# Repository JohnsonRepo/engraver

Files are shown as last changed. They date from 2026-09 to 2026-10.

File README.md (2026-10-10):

# engraver

CNC-Engraver mit Diodenlaser — Konstruktionsskripte, Prüfwerkzeuge und Notizen.

## Aufbau der Maschine

| Ebene | Aufbau |
|---|---|
| Gestell | 2 × 2060 Aluprofil quer (600 mm, 435 mm Mitte zu Mitte, das vordere 35 mm hinter dem Ende der 2040), darauf 2 × 2040 Aluprofil längs (600 mm), alle hochkant; steht auf 4 gedruckten Führungsfüßen 25,3 mm über dem Tisch, dazwischen die Opferplatte |
| Y-Achse | 2 Linearführungen MGN12H (Schienen 500 mm) oben auf den 2040ern; GT2-Riemen in den oberen Nuten der 2040, vorn je Seite ein NEMA 17 mit dem Ritzel direkt auf der Welle, mittig zur 2040 |
| Portal | Y-Schlitten auf den MGN12H-Wagen, dazwischen ein 2020-V-Slot-Profil (500 mm); Y-Schienen 514 mm Mitte zu Mitte |
| X-Achse | Linearführung MGN15H (Schiene 450 mm) am Portalprofil, GT2-Riemen: NEMA 17 links, Umlenkung mit Spanner rechts |
| Z-Achse | Toolhead am MGN15H-Wagen: eigene MGN9-Führung, NEMA 17 über Tr8×2-Spindel |
| Werkzeug | Diodenlaser am Z-Schlitten |
| Steuerung | Arduino Uno R3 + CNC Shield V3 + 4 × TMC2209 (vorhanden), GRBL 1.1, A-Achse klont Y; ohne PC über einen Raspberry Pi Zero 2 W mit CNCjs |

## Inhalt

```
fusion/ToolheadZ/              Baugruppe: kompletter Toolhead mit Z-Achse  ← aktuell
fusion/Portal/                 Baugruppe: Y-Schlitten, Y-Klemmtürme, X-Antrieb, Y-Antrieb mit Y-Motorhalter, Endschalter X und Y, Wanne der X-Energiekette
fusion/Elektronik/             Gehäuse für Uno + CNC Shield, Wandler, Wago; Deckel als Haube mit Lüfter (Rev. 3)  ← neu
fusion/NotAus/                 Gehäuse für den Not-Aus vorn am vorderen 2060  ← neu
fusion/Kabelhalter/            Kabelhalter für die untere Seitennut außen an den 2040  ← neu
fusion/PiHalter/               Halter mit Haube für Pi Zero 2 W und 5-V-Wandler an der Rückseite des hinteren 2060  ← neu
fusion/Opferplatte/            Führungsfüße unter den 2060 und Riegel für die Opferplatte (Spanplatte)  ← neu
fusion/Spannmittel/           Anschlagwinkel, Exzenter und Niederhalter für das Werkstück auf der Opferplatte  ← neu
fusion/ToolheadGrundplatte/    nur die Laserplatte (vom Toolhead überholt)
stl/                           druckfertige STL ohne Fusion: Kasten und Haube des Elektronik-Gehäuses, Kabelhalter, Pi-Halter und seine Haube
pi/                            Pi: Einrichtungsskript, CNCjs-Konfiguration mit Makros, Dienst, sudoers, WLAN-Energiesparen aus
docs/toolhead-z.md             Maßkette, Antrieb, Montage, Druck, Prüfliste
docs/portal-y-schlitten.md     Y-Schlitten, Y- und X-Riemen, Klemmen, Montage, Druck
docs/portal-y-schlitten.svg    Draufsicht auf beide Portalenden, Schnitte durch Klemmen und Umlenkung
docs/toolhead-z-layout.svg     maßstäbliche Seiten- und Vorderansicht
docs/toolhead-z-antrieb.svg    Skizze des Z-Antriebs: Motor, Kupplung, Spindel, Garnitur
docs/toolhead-grundplatte.md   Doku der Einzelplatte
docs/elektronik.md             Platz, Gehäuse, Leistung, Endschalter, Kabel, Anschlussplan
docs/elektronik-platz.svg      Draufsicht und Seitenansicht: Elektronikfach, Ketten, Kabelwege
docs/elektronik-anschluss.svg  Anschlussplan mit Kabelnummern W1–W19 und Kabelliste
docs/elektronik-verkabelung.svg  Verkabelung Schritt für Schritt: jede Ader von Klemme zu Klemme
docs/motoren-anschluss.svg     Motoren anschließen: Steckplätze am Shield, Adern je Achse
docs/verkabelung.md            Verkabelung: Kabelliste, Anschlussliste, Klemmen, Schritt für Schritt, Inbetriebnahme, GRBL
docs/elektronik-box.svg        Elektronik-Gehäuse von oben: Uno, Lüfter, Verteiler, Kabelwege
docs/endschalter.md            Endschalter X und Y: Halter, Fahnen, Montage, Einstellen, GRBL
docs/endschalter.svg           Endschalter: Y von hinten und von außen, X von vorn und von oben, Klammer X
docs/notaus.md                 Not-Aus: Taster, Lage, Gehäuse, Montage, Druck
docs/notaus.svg                Not-Aus-Gehäuse von vorn, im Schnitt und von oben
docs/kabelhalter.md            Kabelhalter: Rinne, Kabel, Plätze links und rechts, Montage, Druck
docs/kabelhalter.svg           Kabelhalter im Schnitt am 2040 und seine Plätze
docs/pi.md                     Pi: Maschine ohne PC über CNCjs — Teile, Halter, Strom, Einrichten, LightBurn, Ablauf, Fehlersuche
docs/pihalter.svg              Pi-Halter mit Haube von hinten und im Schnitt am 2060
docs/opferplatte.md            Opferplatte, Führungsfüße und Riegel: Lage, Höhen, Montage, Druck
docs/opferplatte.svg           Gestell von oben mit Platte, Füßen und Riegel, Schnitte durch Füße, Riegel und Anschlag
docs/spannmittel.md            Werkstück spannen: Anschlag als Nullpunkt, Exzenter, Niederhalter, Höhe unter dem Toolhead
docs/spannmittel.svg           Ecke der Opferplatte mit Spannmitteln von oben, Schnitte durch Niederhalter und Anschlag, Exzenter
docs/hardware-notizen.md       Kaufteilmaße mit Verifizierungsstatus
docs/ausrichten.md             Gestell und Y-Achse mit einer Winkel-Messbox ausrichten
docs/y-motorhalter.md          Y-Antrieb: Riemen in der Nut, Aufbau, Spannen, Montage, Druck
docs/y-motorhalter.svg         Y-Motorhalter: Draufsicht, Seitenansicht, Schnitt, Riemen in der Nut
docs/energiekette.md           Energieketten X und Y (gedruckt): Kette, Lage, Halter, Wannen, Stützen, Träger, Kabelweg, Montage, Druck
docs/energiekette.svg          X-Energiekette von vorn, im Schnitt durch eine Wannenstütze und durch den Kabelflügel
docs/energiekette-y.svg        Y-Energiekette von links und im Schnitt durch einen Träger
tools/bauraum.py               Bauräume als Quader — Quelle für Prüfung + Zeichnung
tools/toolhead_check.py        rechnerische Prüfung der Baugruppe (ohne Fusion)
tools/portal_check.py          Prüfung des Portals mit dem Toolhead über X- und Z-Weg
tools/layout_zeichnen.py       erzeugt die Layout-Zeichnung
tools/antrieb_zeichnen.py      erzeugt die Antriebsskizze
tools/portal_zeichnen.py       erzeugt die Portalzeichnung
tools/elektronik_check.py      Prüfung des Elektronikgehäuses (Fach, Freiraum, Montage, Druck, Leistung, Litzen) und der Verkabelung
tools/elektronik_zeichnen.py   erzeugt die Elektronik-Zeichnung und die Kabellängen
tools/anschluss_zeichnen.py    erzeugt den Anschlussplan
tools/verkabelung_zeichnen.py  erzeugt das Bild „Verkabelung Schritt für Schritt“
tools/motoren_zeichnen.py      erzeugt das Bild „Motoren anschließen“
tools/verkabelung.py           Kabelliste — Quelle für Anleitung, Anschlussplan und Prüfung; schreibt die Tabellen in docs/verkabelung.md
tools/elektronik_box_zeichnen.py erzeugt die Draufsicht auf das Elektronik-Gehäuse
tools/endschalter_check.py     Prüfung der Endschalter: Schaltpunkte, Blatt im Spalt, Freiraum über den ganzen Weg
tools/endschalter_zeichnen.py  erzeugt die Zeichnung der Endschalter
tools/notaus_check.py          Prüfung des Not-Aus-Gehäuses: Lage, Freiraum, Schrauben, Taster, Druck
tools/notaus_zeichnen.py       erzeugt die Zeichnung des Not-Aus-Gehäuses
tools/kabelhalter_check.py     Prüfung der Kabelhalter: Schraube, Rinne und Kabel, Plätze, Freiraum, Druck; schreibt die Plätze in docs/kabelhalter.md
tools/kabelhalter_zeichnen.py  erzeugt die Zeichnung der Kabelhalter
tools/pihalter_check.py        Prüfung des Pi-Halters: Lage, Freiraum zu Portal, Kasten und Kabeln, Schrauben, Pi, Wandler, Haube, Druck
tools/pihalter_zeichnen.py     erzeugt die Zeichnung des Pi-Halters
tools/stl_export.py            schreibt stl/ aus denselben Maßen wie die Fusion-Skripte (braucht manifold3d)
tools/opferplatte_check.py     Prüfung von Opferplatte, Füßen und Riegel: Arbeitsfeld, Höhen, Freiraum, Riegel, Schrauben, Druck
tools/opferplatte_zeichnen.py  erzeugt die Zeichnung von Opferplatte, Füßen und Riegel
tools/spannmittel_check.py     Prüfung der Spannmittel: Höhe unter dem Toolhead, Lage, Selbsthemmung, Schrauben, Druck
tools/spannmittel_zeichnen.py  erzeugt die Zeichnung der Spannmittel
tools/kette_zeichnen.py        erzeugt die Zeichnung der X-Energiekette
tools/geometrie_check.py       Prüfung der Einzelplatte
tools/y_motorhalter_check.py   rechnerische Prüfung des Y-Motorhalters
tools/y_motorhalter_zeichnen.py erzeugt die Zeichnung des Y-Motorhalters
```

## Teile

### Toolhead Z-Achse (aktuell)

Kompletter Toolhead als Baugruppe aus sieben gedruckten Teilen: **Trägerplatte**
am MGN15H-Wagen des Portals — mit angeformter Motorkonsole für den NEMA 17 —,
ein **Motoradapter**, der den Motor 10 mm über die Konsole hebt,
**Schlittenplatte** auf dem MGN9H-Z-Wagen mit dem Laser, ein **Mutternwinkel**
als Flanschsitz für die Tr8×2-Anti-Backlash-Garnitur, schwimmend verschraubt,
eine schwarze **Schaltfahne** und ein **Endschalterhalter** für die
Gabellichtschranke, dazu der **Riemenhalter** hinten an der Trägerplatte, der
beide Enden des X-Riemens klemmt (Rev. 33).

Nutzbarer Z-Verfahrweg **93,6 mm** (MGN9-Schiene 200 mm), Strahlachse 58,5 mm
vor der X-Wagen-Stirnfläche, NEMA 17 mit allen vier Schrauben zugänglich. Die
Laserhöhe ist über senkrechte Langlöcher ±8 mm verstellbar, damit der
Fokusabstand des Moduls nicht in der Geometrie steckt. Werkstückhöhe bis 59 mm
— begrenzt nicht vom Verfahrweg, sondern von der Plattenunterkante, die in X
mitfährt — die 200-mm-Spindel wird dafür auf 160 mm gekürzt. Details in
[docs/toolhead-z.md](docs/toolhead-z.md).

### Portal: Y-Schlitten, X- und Y-Antrieb (neu)

Riemenklemmenschlitten für die **MGN12H-Wagen (20 × 20)**, links und rechts
gespiegelt. Sie tragen das Portalrohr von unten und verschrauben es hinten
(Rückwand, 2 × M5 in Hammermuttern) und an der Stirn (M5 in die
Kernbohrung) — die Vorderseite bleibt frei für die X-Schiene. Unter jeder
Platte hängen **zwei gleiche Klemmtürme wie bei v8** mit Rippen und
Querstift, einer je Riemenende — seit Rev. 25 dicht an der 2040, damit
der Y-Riemen in die Nut läuft, seit Rev. 27 unter den Gewindeeinsätzen
schmal, seit Rev. 28 an der engsten Stelle 1 mm neben der 2040.
Links steht der **X-Motor** über dem Rohrende — so tief, dass seine
20-mm-Welle das ganze Ritzel trägt —, rechts die **Umlenkung**: ein Ritzel
wie am Motor auf einer Welle in Kugel- und Gleitlager, beide in einem
Lagerschlitten, den eine M3 nach außen zieht (seit Rev. 18). Vorn an jedem 2040
sitzt der [Y-Motorhalter](#y-motorhalter-neu) mit dem Y-Motor, seit Rev. 16
ebenfalls aus `Portal.py`. Aluprofile, Linearführungen,
Riemen und Motoren stehen als Referenz mit im Modell (Komponente
`Referenz_nicht_drucken`, nur zur Ansicht).

X-Weg **391,2 mm** — die ganze Schiene minus Wagen. Der Toolhead fährt an
beiden Enden mit mindestens 3 mm an Motor, Umlenkung, Schlitten und Y-Riemen
vorbei, geprüft über den ganzen X- und Z-Weg. Details in
[docs/portal-y-schlitten.md](docs/portal-y-schlitten.md).

### Y-Motorhalter (neu)

Hält vorn an jeder 2040 einen NEMA 17, dasselbe Teil links und rechts. Der
Y-Riemen läuft in den oberen Nuten beider Seitenflächen und am Profilende um
das Ritzel, das direkt auf der Motorwelle sitzt. Der Motor hängt mittig zur
2040 unter einer Platte, Welle nach oben. Mit 20 Zähnen laufen beide Trume
mittig im Nutkanal. Der Halter ist ein U-Bügel: zwei Schenkel mit 4 × M5 in
den unteren Nuten, ein Joch liegt an der Stirnseite an. Gespannt wird über
Langlöcher, der Motor rückt ±4 mm vom Profil weg. Gedruckt wird kopfüber
ohne Stützen. Seit Portal Rev. 16 baut ihn `Portal.py` mit (vorher das
eigene Skript `YMotorhalter.py`); den alten Halter des Portals, Achse
15,55 mm neben der Profilmitte, gibt es nicht mehr. Details in
[docs/y-motorhalter.md](docs/y-motorhalter.md).

### Elektronikgehäuse (neu)

Gehäuse im Fach hinter dem hinteren 2060, unter den 2040 — dorthin fährt
weder Portal noch Toolhead. Links der **Arduino Uno mit CNC Shield V3** auf
Stehbolzen, USB nach hinten zum Pi; rechts der **Abwärtswandler 24 → 12 V** für den
Laser (43 × 24 × 20 mm) und drei **Wago-Klemmen** (221-415 für +24 V,
2 × 221-420 für GND und +5 V); hinten **Einbaubuchse** (Hohlstecker
5,5 × 2,1) und runder **Schalter** (Blende Ø22,5, seit Rev. 4). Der
**Deckel** trägt den 24-V-Lüfter über den Treibern. Seit Rev. 3 ist er
eine Haube, deren Platte 25 mm höher liegt. Eine Montageplatte hängt es mit 4 × M5 an die Rückseite des 2060,
dazwischen läuft ein Kabelkanal. Dazu Endschalter, Kabelwege, Energieketten,
Leistungsbilanz des 72-W-Netzteils und der Anschlussplan in
[docs/elektronik.md](docs/elektronik.md).

### Verkabelung (neu)

Alle 19 Leitungen vom Steckernetzteil bis zum Laser und zum Pi mit Nummer, Adern,
Farben, Querschnitt, Weg und Kauflänge; Belegung der Wago-Klemmen und des
Shields; Material, Reihenfolge beim Anschließen und eine Inbetriebnahme in
Stufen (24 V, Wandler, GRBL und Lichtschranken, Vref, Motoren,
Referenzfahrt, Laser, Not-Aus) mit den GRBL-Einstellungen. Neu gegenüber
dem alten Plan: Pull-down 10 kΩ auf der Laser-PWM, 24-V-Wächter an
Abort, Masse der Lichtschranken über die Wago. Dazu ein Bild, das jeden
der acht Schritte für sich zeigt, jede Ader von Klemme zu Klemme in ihrer
Farbe ([elektronik-verkabelung.svg](docs/elektronik-verkabelung.svg)).
Details in [docs/verkabelung.md](docs/verkabelung.md).

### Pi und Pi-Halter (neu)

Ein **Raspberry Pi Zero 2 W** mit [CNCjs](https://cnc.js.org/) ersetzt den
PC am USB des Uno. LightBurn auf dem Mac speichert Aufträge als G-Code-Datei,
gestartet werden sie im Browser am iPad, iPhone oder Mac. Der Pi schickt die
Datei selbst an den Uno, ein Abbruch des WLAN hält den Auftrag nicht an.
Er hängt mit einem **5-V-Wandler** vor Schalter und Not-Aus an der Buchse
(W18, W19) und versorgt über USB den Uno (W17). Not-Aus und Schalter
trennen weiter Motoren, Laser und Lüfter, der 24-V-Wächter meldet es an
GRBL. Pi und Wandler sitzen auf einem gedruckten **Pi-Halter** rechts neben
dem Elektronikgehäuse, mit 2 × M5 in der oberen Nut des hinteren 2060.
Der Pi liegt ganz über dem 2060, vor seiner Antenne ist kein Aluminium.
Seit Rev. 3 deckt eine **Haube** Pi und Wandler ab wie beim
Elektronikgehäuse: 3 × M3 in Messing-Einsätzen, unten offen für Kabel und
Luft, Lüftungsschlitze oben.
Die Software in [`pi/`](pi) richtet ein Skript ein (CNCjs 1.11.5 als
Dienst, Makros für Rahmen und Laserpunkt, Herunterfahren aus dem Browser).
Details in [docs/pi.md](docs/pi.md).

### Not-Aus (neu)

Pilztaster mit einem Wechsler (C, NO, NC): C und NC liegen in der
24-V-Leitung, NO bleibt frei. Er sitzt in einem gedruckten Gehäuse vorn am
vorderen 2060, rechts innen neben dem rechten 2040, mit 2 × M5 in der
mittleren Nut und längs verschiebbar. Das Gehäuse ist hinten offen,
45°-Rippen tragen die Laschen, und es druckt ohne Stützen. Dass die 24 V
fehlen, meldet ein Spannungsteiler an Abort, und GRBL bricht ab. Details
in [docs/notaus.md](docs/notaus.md).

### Kabelhalter (neu)

Die fest verlegten Kabel passen nicht in die untere Seitennut der 2040.
Neun gedruckte Halter, links fünf und rechts vier, hängen deshalb mit je
einer M5×10 in einer Hammermutter an der Nut. Eine Feder in der Nutöffnung
richtet sie aus. Darunter liegt eine offene Rinne (13 × 12 mm) mit Lippe,
in die die Kabel von oben fallen. Sie liegt 1 mm unter den Wänden der
Träger Y, die Kabel laufen dort also gerade durch. Links und rechts ist es
derselbe Halter, gedruckt liegend und ohne Stützen. Plätze und Kabel stehen
in [docs/kabelhalter.md](docs/kabelhalter.md).

### Opferplatte und Führungsfüße (neu)

Die Opferplatte ist eine Spanplatte 615 × 349 × 25 mm (gemessen 25,3 mm
dick). Sie liegt auf dem
Tisch zwischen vier gedruckten **Führungsfüßen** unter den Enden der
beiden 2060. Die Füße sind so hoch, wie die Platte dick ist: Ihre
Oberfläche liegt dort, wo bisher der Tisch war, und Fokus und
Werkstückhöhe (58 mm) bleiben. Jeder Fuß greift mit einer Feder in die
untere Nut und hält mit einem Flansch und 2 × M5 in Hammermuttern der
unteren Seitennut. Innen führen die Füße die Platte, links sitzt der
Anschlag, nach rechts wird sie herausgezogen. Dort hält sie ein
**Klappriegel** auf einer M5 längs X. Ein Stoß gegen die Platte drückt
ihn längs der Achse an seinen Lagerbock und kann ihn nicht aufklappen;
zum Herausnehmen klappt man ihn nach vorn um. Details in
[docs/opferplatte.md](docs/opferplatte.md).

### Spannmittel (neu)

Ein Laser drückt nicht auf das Werkstück. Gespannt wird, damit es an einer
bekannten Stelle liegt, nicht verrutscht und dünnes, verzogenes Material
flach bleibt. Ein **Anschlagwinkel** sitzt fest hinten links auf der
Opferplatte, seine Innenecke ist der Nullpunkt (`G10 L20 P1 X0 Y0`). Zwei
selbsthemmende **Exzenter** schieben das Werkstück in die Ecke, und
**Niederhalter** je Materialstärke (2–6 mm) halten dünne Platten am Rand
flach. Alles ist so flach, dass der Toolhead darüberfährt: Anschlag und
Exzenter sind 3 mm hoch, der Niederhalter ragt 2,5 mm über das Werkstück,
und der Toolhead bleibt mindestens 3,7 mm darüber. Befestigt wird mit
Spanplattenschrauben 3,0 × 20. Details in
[docs/spannmittel.md](docs/spannmittel.md).

### Endschalter X und Y (neu)

Zwei LM393-Gabellichtschranken wie an Z, beide schalten 3 mm vor dem
Schienenende. **Y** sitzt außen am rechten 2040, 35 mm hinter dem hinteren
2060, mit 2 × M5 in der unteren Nut; die obere trägt den Rücklauf des
Y-Riemens. Die Fahne ist eine Klammer an der rechten Schlittenplatte.
**X** sitzt auf einem Block vor dem linken Rohrende, der an das Ende der
X-Schiene stößt und zugleich Anschlag ist. Die Fahne sitzt auf einer
Klammer unten an der Trägerplatte und ist im Langloch ±2 mm verstellbar.
Fahnen und Klammern werden schwarz gedruckt. Details in
[docs/endschalter.md](docs/endschalter.md).

### Energieketten X und Y (neu)

Beide Energieketten sind gedruckt (Modell „Energiekette“, Teilung 16,
außen 18 × 14 mm, R 20). Die X-Kette liegt direkt hinter der Trägerplatte. Der Festpunkt
sitzt in der Mitte des X-Wegs auf einer **Wanne** über dem Portalrohr, die
Schleife zeigt nach rechts. Drei **Stützen** halten die Wanne. Sie sitzen mit
je einer M5 in der hinteren Nut des Rohrs und reichen über X-Riemen und
Riemenhalter. Am Toolhead trägt ein **Kettenhalter** über dem Riemenhalter
das bewegte Ende. 17 Glieder reichen, am rechten Ende läuft der Bogen
3,25 mm über den Lagerschlitten. Wanne und Stützen baut `Portal.py`
(seit Rev. 19), den Kettenhalter `ToolheadZ.py` (seit Rev. 35), mit einer
Bohrlehre für die schon gedruckte Trägerplatte. Seit Portal Rev. 22 und
ToolheadZ Rev. 37 rechnen beide wieder mit R 20: Die Schleife der
gedruckten Kette ist außen 50 mm hoch (gemessen). Seit Portal Rev. 21 laufen die Litzen in der
oberen Nut des Rohrs zum Festpunkt, ein **Kabelflügel** an der Stütze hält
sie mit zwei Kabelbindern. Die **Y-Kette** (16 Glieder) liegt außen am
linken 2040: Ihr bewegtes Ende trägt ein **Kettenhalter Y** auf dem linken
Schlitten, der Untertrum läuft in einer **Wanne Y** auf drei **Trägern** an
der unteren Seitennut, die Schleife zeigt nach vorn. Details in
[docs/energiekette.md](docs/energiekette.md).

### Toolhead-Grundplatte (überholt)

Die erste Ausführung: nur die Platte, die den Laser am MGN9-Z-Wagen hält, ohne
Z-Antrieb. Das Konzept — Auflagepad, das die Montagehöhe des Wagens aufnimmt —
steckt unverändert in der Schlittenplatte des Toolheads.
Siehe [docs/toolhead-grundplatte.md](docs/toolhead-grundplatte.md).

## Skript in Fusion ausführen

Den Ordner unter `fusion/` (`.py` **und** `.manifest`) hierhin kopieren:

* macOS: `~/Library/Application Support/Autodesk/Autodesk Fusion 360/API/Scripts/`
* Windows: `%APPDATA%\Autodesk\Autodesk Fusion 360\API\Scripts\`

Dann in Fusion *Utilities → Scripts and Add-Ins → ToolheadZ → Run* (bzw.
*Portal*, *Elektronik*, *NotAus*, *Kabelhalter*, *PiHalter*, *Opferplatte* oder *Spannmittel*). Jeder Lauf legt ein **neues
Dokument** an, das aktive bleibt unberührt. Am Ende erscheint
ein Validierungsbericht mit Maßkette, Verfahrweg, Schraubenliste und
Montagereihenfolge.

## Prüfen und zeichnen

```sh
python3 tools/toolhead_check.py     # Maßkette, Kollisionen, Schrauben, Druck
python3 tools/portal_check.py       # Portal + Toolhead über den ganzen Weg
python3 tools/elektronik_check.py   # Elektronikgehäuse gegen Portal, Toolhead, Rahmen; Verkabelung
python3 tools/layout_zeichnen.py    # docs/toolhead-z-layout.svg neu erzeugen
python3 tools/antrieb_zeichnen.py   # docs/toolhead-z-antrieb.svg neu erzeugen
python3 tools/portal_zeichnen.py    # docs/portal-y-schlitten.svg neu erzeugen
python3 tools/elektronik_zeichnen.py # docs/elektronik-platz.svg + Kabellängen
python3 tools/anschluss_zeichnen.py  # docs/elektronik-anschluss.svg
python3 tools/verkabelung_zeichnen.py # docs/elektronik-verkabelung.svg
python3 tools/motoren_zeichnen.py     # docs/motoren-anschluss.svg
python3 tools/verkabelung.py         # Tabellen in docs/verkabelung.md
python3 tools/elektronik_box_zeichnen.py  # docs/elektronik-box.svg
python3 tools/geometrie_check.py    # nur die Einzelplatte
python3 tools/y_motorhalter_check.py  # Y-Motorhalter: Riemen in der Nut, Freigänge, Schrauben
python3 tools/y_motorhalter_zeichnen.py  # docs/y-motorhalter.svg neu erzeugen
python3 tools/endschalter_check.py  # Endschalter: Schaltpunkte, Freigänge, Schrauben, Druck
python3 tools/endschalter_zeichnen.py  # docs/endschalter.svg neu erzeugen
python3 tools/notaus_check.py       # Not-Aus-Gehäuse: Lage, Freiraum, Schrauben, Druck
python3 tools/notaus_zeichnen.py    # docs/notaus.svg neu erzeugen
python3 tools/kabelhalter_check.py  # Kabelhalter: Schraube, Rinne, Plätze, Freiraum (--doku: Tabelle neu)
python3 tools/kabelhalter_zeichnen.py  # docs/kabelhalter.svg neu erzeugen
python3 tools/pihalter_check.py     # Pi-Halter: Lage, Freiraum, Schrauben, Pi, Wandler, Haube, Druck
python3 tools/pihalter_zeichnen.py  # docs/pihalter.svg neu erzeugen
pip install manifold3d && python3 tools/stl_export.py  # stl/ neu: Kasten, Haube, Kabelhalter, Pi-Halter und seine Haube in Drucklage (mit Namen, z. B. PiHalter: nur diese)
python3 tools/opferplatte_check.py  # Opferplatte, Füße, Riegel: Feld, Höhen, Freiraum, Schrauben
python3 tools/opferplatte_zeichnen.py  # docs/opferplatte.svg neu erzeugen
python3 tools/spannmittel_check.py  # Spannmittel: Höhe unter dem Toolhead, Lage, Exzenter, Schrauben
python3 tools/spannmittel_zeichnen.py  # docs/spannmittel.svg neu erzeugen
python3 tools/kette_zeichnen.py     # docs/energiekette.svg und energiekette-y.svg neu erzeugen
```

`toolhead_check.py` importiert das Fusion-Skript mit gestubbtem `adsk`-Modul und
prüft dieselbe Maßkette, die das Skript zum Bauen verwendet: Y-Kette,
Verfahrweg mit allen vier Begrenzungen, Kollisionen über 21 Stellungen des
Verfahrwegs, Materialstege, Schraubenlängen und -eingriffstiefen,
**Werkzeugzugang für jede Schraube** (freie Inbus-Länge im Zustand, in dem sie
verschraubt wird), Lochbildtoleranzen, Druckbarkeit — und statisch, dass jeder
im Skript benutzte Maß- und Lageschlüssel existiert. Exit-Code 0 = alles
bestanden.

`portal_check.py` importiert beide Skripte und fährt den Toolhead über
81 X- × 11 Z-Stellungen gegen Schlitten, Motor, Umlenkung, beide Riemen und
den Rahmen; dazu Riemenlage, Klemmung, Spannwege, Wände, Schraubenlängen,
Werkzeugzugang und Druckbarkeit der Portalteile, den Y-Weg gegen die 2060
und die Y-Motorhalter, den Y-Antrieb selbst mit dem Riemenweg über den
ganzen Y-Weg, das Elektronikfach hinter
dem hinteren 2060, in das weder Portal noch Toolhead hineinfahren, die
X-Energiekette mit Wanne und Stützen über den ganzen X-Weg samt Kabelweg
und die Y-Energiekette mit Halter, Wanne und Trägern über den ganzen
Y-Weg.

**Stand:** alle Prüfungen bestanden (ToolheadZ Rev. 38, Portal Rev. 28 mit
dem Y-Motorhalter, `y_motorhalter_check.py`, Opferplatte Rev. 3,
Spannmittel Rev. 1). Neu ist Portal Rev. 28: Die Klemmtürme aus Rev. 26/27
streiften an der engsten Stelle an der 2040. Rev. 26 hatte die an einer
Stelle gemessenen 3,0 statt 2 mm Luft für den ganzen Weg angenommen. Jetzt
stehen die Türme an der engsten Stelle 1 mm neben der 2040, an der
weitesten 2 mm (`kt_luft_mehr` 0, `kt_luft_streuung` 1 mm). Die
Riemenmitte liegt 3,9 bis 4,9 mm vor der Seitenfläche, der vordere Trum
taucht auch an der weitesten Stelle in die Nut. Nur die vier Klemmtürme
neu drucken, die Stifte bleiben
([portal-y-schlitten.md](docs/portal-y-schlitten.md#1-mm-neben-der-2040-seit-rev-26)).
Davor kam Portal Rev. 27: Die Klemmtürme sind nur noch oben, im Block um
die Gewindeeinsätze, so breit wie bisher; darunter ist die Wand innen neben
dem Riemen 5,4 statt 12,2 mm dick. Der Querstift wurde ein Ø3 × 8 oder
M3×8, ein Turm braucht gut ein Drittel weniger Material
([portal-y-schlitten.md](docs/portal-y-schlitten.md#schmaler-unter-den-einsätzen-seit-rev-27)).
Davor kam Portal Rev. 26: Die Klemmtürme rückten 2 mm an die 2040 heran,
der Querstift steckt seitdem in einem Sackloch und kann nicht zur 2040
hinauswandern.
Davor kam Portal Rev. 25: Die Y-Klemmtürme rückten von 7,2 mm an die 2040
heran, damit der Riemen in die obere Nut läuft.
Davor kam `Spannmittel.py`: Anschlagwinkel als
Nullpunkt, Exzenter und Niederhalter für das Werkstück, alles flach genug
für den Toolhead. Davor kam `Opferplatte.py`: vier Führungsfüße für die Spanplatte 615 × 349 × 25 mm,
seit Rev. 2 so hoch wie ihre gemessenen 25,3 mm; die Maschine steht
darauf, die Plattenoberfläche liegt auf der alten Tischhöhe. Rev. 3 hält
die Platte an der offenen rechten Seite mit einem Klappriegel, den ein
Ausleger am Fuß vorn rechts trägt. Portal Rev. 24
stellt auf den
linken Stirnblock einen Anschlag für den X-Motorhalter: Bis dahin hielt
ihn nur die Reibung unter seinen zwei Schrauben, und bei kräftig
gespanntem Riemen rutschte er nach innen. Der gedruckte Halter passt
weiter, neu gedruckt wird nur der linke Schlitten. Portal Rev. 23 und ToolheadZ
Rev. 38 geben der Kette 0,5 mm Spiel je Seite in Wannen und Kettenhaltern
(vorher 0,3); die X-Kette liegt dafür 0,2 mm weiter hinten. Der linke
Schlitten hat die zwei Löcher für den Kettenhalter Y im Modell (seit
Rev. 21, für einen Neudruck), in den schon gedruckten bohrt man sie mit
der Bohrlehre. Portal Rev. 22 und ToolheadZ
Rev. 37 rechnen die Ketten wieder mit R 20, nach der gemessenen Schleife
(außen 50 mm, 4 Gelenke im Bogen): X 17, Y 16 Glieder, der Kettenhalter
24 mm tiefer, die Wanne Y 24 mm höher. Portal Rev. 21 bringt die
gedruckte Y-Energiekette (Kettenhalter Y, Wanne Y, drei Träger)
und den Kabelweg zur X-Kette in der oberen Nut mit dem Kabelflügel am
Festpunkt ([energiekette.md](docs/energiekette.md)). Portal Rev. 19 und ToolheadZ
Rev. 35 bringen die gedruckte X-Energiekette: Wanne mit Festpunkt und drei
Stützen am Portalrohr, Kettenhalter an der Trägerplatte
([energiekette.md](docs/energiekette.md)). Portal Rev. 20 und ToolheadZ
Rev. 36 rechneten sie mit R 32, nach einer Schätzung von 30° je Glied.
Portal Rev. 18 lenkt den
X-Riemen mit einem Ritzel auf einer Welle um, die in Kugel- und Gleitlager
im Lagerschlitten läuft; Spannbock und Schlitten ersetzen Umlenkhalter und
Spannklotz (ToolheadZ Rev. 34 ändert dazu nur einen Kommentar). Portal
Rev. 14 legt das
hintere 2060 nach der Messung 435 mm hinter das vordere (die 2040 stehen
hinten 110 mm über); nach hinten begrenzt jetzt das Schienenende den Y-Weg.
Elektronikgehäuse Rev. 2 mit den am Aufbau gemessenen Werten (Stapelhöhe,
Wandler, Wago) gezeichnet, geprüft und gedruckt, seit Rev. 3 mit einer
höheren Haube als Deckel, seit Rev. 4 mit rundem Schalterloch
([elektronik.md](docs/elektronik.md)). Die Endschalter X und Y baut seit
Rev. 15 `Portal.py` mit, geprüft mit `endschalter_check.py`
([endschalter.md](docs/endschalter.md)),
Not-Aus-Gehäuse Rev. 5 mit `notaus_check.py` ([notaus.md](docs/notaus.md)),
Kabelhalter Rev. 2 mit `kabelhalter_check.py` ([kabelhalter.md](docs/kabelhalter.md)),
Pi-Halter Rev. 3 mit Haube und `pihalter_check.py` ([pi.md](docs/pi.md)). Die
Verkabelung steht als Kabelliste in `tools/verkabelung.py`,
`elektronik_check.py` prüft sie (Netze, Not-Aus, Kontakte, Klemmen, Längen,
Tabellen in [verkabelung.md](docs/verkabelung.md)). Der
Zugangskonflikt zwischen Laser und Z-Wagen ist gelöst, indem der Laser
30,75 mm tiefer hängt und über senkrechte Langlöcher eingestellt wird —
[Laserhöhe](docs/toolhead-z.md#laserhöhe-langloch-statt-rechnen).

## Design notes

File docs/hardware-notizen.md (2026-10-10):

# Hardware-Notizen (projektlokal)

Ergänzung zur `references/hardware.md` des `fusion-python`-Skills, damit die
Werte dieses Projekts auch ohne den Skill nachvollziehbar sind.

Status: `[v]` am realen Teil verifiziert · `[w]` Datenblatt/Web, ungeprüft ·
`[?]` eigene Messung mit unsicherer Messbasis → im Skript als Langloch ausführen.

## Aufbau der Maschine

| Ebene | Aufbau |
|---|---|
| Gestell | 2 × 2060 Aluprofil quer (600 mm, 435 mm Mitte zu Mitte, das vordere 35 mm hinter dem vorderen Ende der 2040, hinten stehen die 2040 110 mm über), darauf 2 × 2040 Aluprofil längs (600 mm), alle hochkant; an jeder Kreuzung 8 Winkel (20 mm). Seit 2026-10-02 auf 4 gedruckten Führungsfüßen 25,3 mm über dem Tisch ([opferplatte.md](opferplatte.md)) |
| Opferplatte | **Spanplatte 615 × 349 × 25 mm**, gemessen **25,3 mm** dick, Länge 615 bestätigt (`[v]` Angabe und Messung 2026-10-02; notfalls an der Kreissäge kürzbar), liegt zwischen den Führungsfüßen auf dem Tisch, Oberfläche auf der Unterkante der 2060; wird nach rechts herausgezogen, dort hält sie seit Rev. 3 ein Klappriegel |
| Y-Achse | 2 Linearführungen **MGN12H** (Schienen 500 mm) oben auf den 2040ern; GT2-Riemen in den oberen Nuten der 2040, vorn **je Seite ein NEMA 17** mit dem Ritzel direkt auf der Welle, mittig zur 2040 (Y-Motorhalter in `Portal.py`) |
| Portal | Halterungen auf den Y-Schlitten, dazwischen 2020 V-Slot, 500 mm |
| X-Achse | Linearführung **MGN15H**, Schiene 450 mm am Portalprofil |
| Z-Achse | Grundplatte am X-Wagen, darauf Linearführung; Toolhead auf dem Z-Wagen |
| Werkzeug | Diodenlaser am Toolhead |
| Steuerung | Arduino Uno R3 + CNC Shield V3 + 4 × TMC2209 (vorhanden), GRBL 1.1 — siehe [Elektronik](#elektronik) |

## Z-Achse / Toolhead

| Wert | Maß | Status |
|---|---|---|
| Linearführung Z | **MGN9H** | `[v]` am 2026-09-17 mit Bohrlehre geprüft |
| Schienenlänge | **200 mm** | `[v]` vorhandene Schiene |
| Randabstand / Lochabstand | **10 / 20 mm** → 10 Löcher | `[v]` gemessen |
| Wagen-Lochbild | **15 quer × 16 längs** | `[v]` |
| Montagehöhe Wagen | 10 mm über der Schienen-Auflageebene | `[w]` |
| Schiene MGN9 | 9 breit × 6,5 hoch | `[w]` |
| Gewindetiefe im Wagen | ~2,5 mm (M3) → max. M3×8 bei 6 mm Pad | `[w]` |

**Widerspruch aufgelöst.** `hardware.md` notierte eine Messung am
„Toolhead-Wagen" von 26 längs × 25 quer, was nicht zu MGN9 passt. Die Bohrlehre
am Z-Wagen hat am 2026-09-17 das äußere Lochpaar (16 mm) bestätigt — die
Z-Achse ist also **MGN9H**. Die 26 × 25 gehören folglich zum Wagen der
**Portalführung** (X-Achse), wo MGN15H = 25 × 25 passt. Am 2026-09-21 hat
`Bohrlehre_XWagen` dort gepasst `[v]`: es ist ein **MGN15H mit 25 × 25**
(ein MGN15C hätte 25 × 20), und die 26 × 25 sind damit auch als Messung des
X-Wagens widerlegt — 1 mm Abweichung lässt eine Ø3,4-Lehre auf M3 nicht durch.

Die `Bohrlehre_ZWagen` trug bis dahin beide MGN9-Lochbilder (10 und 16 mm
längs), um die Baugröße zu entscheiden. Sie folgt jetzt dem Parameter
`z_wagen_loch_laengs` und hat nur noch vier Löcher.

## Portalführung (X-Achse)

| Wert | Maß | Status |
|---|---|---|
| Linearführung X | **MGN15H** | `[v]` am 2026-09-21 mit `Bohrlehre_XWagen` geprüft |
| Wagen-Lochbild | **25 × 25 mm** | `[v]` am 2026-09-21 geprüft |
| Wagen | 32 breit (in Z) × 58,8 lang (in X) | `[w]` |
| Montagehöhe Wagen | 16 mm über der Profilfläche | `[w]` |
| Gewindetiefe im Wagen | 4 mm (M3) → M3×12 mit Scheibe | `[w]` |

Damit ist das Lochbild der Trägerplatte bestätigt — sie trägt den ganzen
Toolhead und war das letzte Teil, das auf eine Messung gewartet hat.

## Y-Achse und Portal

| Wert | Maß | Status |
|---|---|---|
| Linearführung Y | **MGN12H**, Lochbild **20 × 20** (Breite 27, Länge 45,4) | `[v]` aus RiemenklemmeSchlitten v8 (.3mf), passt am Wagen |
| Portalprofil | 2020 **V-Slot**, **500 mm** | `[v]` |
| X-Schiene | MGN15, **450 mm** | `[v]` |
| Riemen, Ritzel | GT2 6 mm, **20 Z** | `[v]` |
| Umlenkrollen | **glatt, Bohrung 5 mm**; 20-Z-Ritzel mit Kugellager vorhanden | `[v]` |
| X-Umlenkung | **GT2-Ritzel 20 Z wie am Motor** fest auf einer **Welle Ø5**, die oben in einem Rillenkugellager, unten in einem Gleitlager läuft — wie die Y-Umlenkung hinten; beide Lager im Lagerschlitten, Nabe oben. In der Schleife läuft die Zahnseite auf der Umlenkung, eine glatte Rolle gehört auf den Riemenrücken | gewählt (Portal.py Rev. 18, Angabe 2026-09-30; Rev. 17 hatte ein Ritzel mit eingebauten Lagern, Rev. 16 eine 8,5 mm breite Rolle) |
| Lager der X-Umlenkung | Rillenkugellager **10 × 4** (z. B. MR105ZZ), Gleitlager **Ø7 × 8**, Welle **Ø5**, 30 mm lang | Maße Angabe 2026-09-30, Bohrung 5 angenommen `[?]` |
| Motoren | **Stepperonline** NEMA 17, **37 mm** ohne Welle, **60 mm** mit Welle | `[v]` Angabe am Aufbau |
| Motordaten | **17HE15-1504S**: **1,5 A** je Phase, 2,3 Ω, 4,0 mH, 42 Ncm, Körper 38 mm, Welle Ø5 × 23,5 mm, D-Fläche 20 mm lang, 280 g (gemessen 37 / 23 mm, siehe oben) | `[v]` Typ laut Etikett (2026-09-27), Daten `[w]` Datenblatt Stepperonline |
| NEMA 17, Welle | ragt **23 mm** heraus (60 − 37), Ø5. Die Halter sind auf **20 mm** ausgelegt (erste Angabe): so trägt die Welle das ganze Ritzel, die 3 mm mehr stehen frei über | `[v]` Angabe am Aufbau |
| X-Motorhalter am linken Schlitten | rutschte bei kräftig gespanntem X-Riemen nach innen: ihn hielt nur die Reibung unter 2 × M3×35. Seit Portal Rev. 24 liegt er an einem **Anschlag** auf dem Stirnblock an; der gedruckte Halter passt weiter, der linke Schlitten wird neu gedruckt ([portal-y-schlitten.md](portal-y-schlitten.md#anschlag-für-den-motorhalter-seit-rev-24)) | `[v]` Angabe 2026-10-02, Portal.py Rev. 24 |
| Y-Riemen | seit Portal Rev. 28 **13,91 mm innen** neben der Schienenmitte, 3,9 bis 4,9 mm vor der Seitenfläche der 2040 (engste bis weiteste Stelle der Klemmtürme), Zähne zur Schiene; läuft **nur in der oberen Nut** des 2040, mittig: 7 bis 13 mm unter der Profilkante = 20 bis 26 mm unter der Wagenoberseite. Der Riemen läuft in der rechten Nut hin und in der linken zurück (Angabe 2026-09-27), das Ritzel mittig ([Y-Antrieb](#y-antrieb)). Bis Rev. 24 saßen die Klemmen wie bei v8 21,6 mm innen, und der Riemen lief neben der Nut entlang (Foto 2026-10-05); seit Rev. 25 stehen die Klemmtürme dicht an der 2040, seit Rev. 28 an der engsten Stelle 1 mm daneben ([portal-y-schlitten.md](portal-y-schlitten.md#1-mm-neben-der-2040-seit-rev-26)). Der Wagen-Trum läuft schräg von der Klemme in die innere Nut zum Ritzel, der Rücklauf gerade in der äußeren Nut | `[v]` Höhe Angabe am Aufbau, Lage Portal.py Rev. 28 |
| Y-Schienen auf den 2040 | mittig, **etwa 4 mm je Seite** zwischen Schienen- und Profilkante. Am Klemmturm aus Portal Rev. 25 waren aber an einer Stelle **3,0 statt 2,0 mm** Luft zur 2040, die Türme aus Rev. 26/27 streiften an der engsten Stelle: Dort passt das Modell, an der Messstelle sitzen Schiene oder Schrauben etwa 1 mm anders. Portal Rev. 28 rechnet mit `kt_luft_mehr` = 0 (engste Stelle) und `kt_luft_streuung` = 1,0 mm (weiteste) | `[v]` Angabe 2026-10-05, nicht gemessen; Luft am Turm 2026-10-06 (eine Stelle gemessen, an der engsten streiften die Türme) |
| Obere Nut des 2040 | Öffnung beginnt **6 mm unter der Oberkante** (oberer Rand), Mitte 10 mm darunter | `[v]` Angabe am Aufbau |
| Y-Riemen, Führung | an beiden Enden Ritzel mit senkrechter Achse; der **Rücklauf läuft in der oberen Nut des 2040** (9,5 mm neben der Schienenmitte), die Zähne zeigen zur Schiene = Innenseite der Schleife; die Klemme hängt auf Höhe der oberen Nutreihe | `[v]` Angabe am Aufbau, v8 passte |
| Y-Antrieb | Die Y-Riemen liegen spiegelbildlich, die Antriebe vorn drehen **gegenläufig** → **ein Motor je Ecke** statt eines Motors in der Mitte. Das Ritzel sitzt **direkt auf der Motorwelle**, **mittig zur 2040**, im Y-Motorhalter (seit Portal Rev. 16 in `Portal.py`, vorher eigenes Skript `YMotorhalter.py`; [Y-Antrieb](#y-antrieb)). Der Halter aus Portal Rev. 12/13 (Achse 27,5 mm vor der Stirnseite, 15,55 mm innen, M5 in der oberen Nut) ist gedruckt und am Aufbau verworfen. Eckwelle Ø5 mit Lagern und unteres Ritzel entfallen | `[v]` Aufbau, Halter gerechnet |
| Alte Eckwelle vorn | Ø5 Edelstahl, oben Kugellager, unten Gleitlager, zwei 20-Z-Ritzel; Achse **11 mm vor der Stirnseite** des 2040. Dort passt kein Motor: er ragte 10 mm unter das Ende des 2040 | `[v]` Angabe am Aufbau |
| Y-Umlenkung hinten | Ritzel auf einer Edelstahlwelle, Kugellager und Gleitlager; quer **mittig zur 2040**, der Rücklauf läuft also gerade in der äußeren Nut | `[v]` Angabe am Aufbau (mittig: 2026-09-27); Lage 11 mm hinter der Stirnseite angenommen `[?]` (nur Riemenlänge) |
| Y-Riemen, Länge | offen, je Seite **≈ 1276 mm** von Klemme zu Klemme (Portal in der Mitte; an den Schienenenden bis 0,5 mm mehr, weil die Wagen-Trume schräg laufen; bis Portal Rev. 24 bis 2 mm) | gerechnet (Portal.py Rev. 28, mittige Ritzel), hängt an der Lage des hinteren Ritzels |
| Vorderes 2060 | **35 mm** hinter der Stirnseite der 2040 | `[v]` Angabe am Aufbau |
| Hinteres 2060 | die 2040 stehen hinten **110 mm** darüber hinaus (beide Seiten) → **435 mm** Mitte zu Mitte hinter dem vorderen (bis Portal Rev. 13: 400 `[?]`) | `[v]` Angabe am Aufbau 2026-09-27 |
| Winkel 2040 ↔ 2060 | **8 je Kreuzung**, **20 mm** groß; zwei davon greifen in die **obere Nut des 2060** und die **untere Nut der 2040** — die oberen Nuten der 2040 bleiben frei für den Riemen. Ob einer davon vor dem vorderen 2060 an der Seitenfläche sitzt (dort liegt der Y-Motorhalter), ist offen. Über die an den Innenseiten fahren die Klemmtürme mit 2 mm Luft (seit Portal Rev. 25) | `[v]` Angabe am Aufbau 2026-09-27, Größe 2026-09-29 |
| Abstand der Y-Schienen | **514 mm** Mitte zu Mitte = Rohr 500 + 2 × 7 mm; ergibt sich beim Aufbau aus dem verschraubten Portal | gesetzt (Portal.py), Rechnung siehe unten |
| Kernbohrung 2020 V-Slot | Ø4,2 — für die Stirnschraube **M5 schneiden, ≥ 15 mm tief** | `[w]` |
| Hammermuttern | M5, Nut 6, in der hinteren Nut des Portalrohrs | `[w]` |

Das ältere `RiemenklemmeSchlitten.py` trug noch das Lochbild 25 × 25
(MGN15H) — für die Y-Achse falsch, gilt nur für den X-Wagen.

**Mindestabstand der Y-Schienen:** Der Y-Riemen läuft genau in der Höhe, in
der der Toolhead unten am Ende des X-Wegs vorbeifährt. Mit dem Z-Schlitten
ganz unten ragen rechts Mutternwinkel und Winkel-Lasche 44 mm neben die
Wagenmitte, links die Fahnenlasche 27,5 mm. Bei 450 mm Schiene fährt der
Wagen ±195,6 mm; mit 3 mm Luft zum Riemen ergibt das 513,3 mm. Die X-Schiene
sitzt dafür 8 mm nach links versetzt auf dem Rohr, dann sind beide Seiten
gleich. Das gilt, solange der Rahmen unter den Schienen nicht weiter nach
innen ragt als der Riemen (22 mm neben der Schienenmitte).

Umgesetzt in `fusion/Portal/Portal.py`: 514 mm, X-Schiene 8,25 mm nach links
versetzt. `portal_check.py` maß an beiden Enden 3,4 mm zwischen Toolhead und
Y-Riemen, über den ganzen Z-Weg. Seit Portal Rev. 25 läuft der Riemen
weiter außen, seit Rev. 28 sind es 11,1 mm; am nächsten kommt der Toolhead dort Motor,
Umlenkung und Schlittenplatte (3 mm). Details in
[portal-y-schlitten.md](portal-y-schlitten.md).

## Diodenlaser

| Wert | Maß | Status |
|---|---|---|
| Modul | **LASER TREE 4 W**, 450 nm, Fokus einstellbar | `[v]` Angabe (2026-09-25) |
| Versorgung | **12 V, 1,6 A** (1,4–1,8 A) → höchstens 21,6 W | `[v]` Angabe |
| Leistung steuern | PWM mit 5 V — direkt vom Uno (D11) | `[v]` Angabe |
| Anschluss | Buchse **XH2.54, 3-polig**, von links **PWM · GND · +12 V** — vor dem ersten Einschalten mit dem Aufdruck vergleichen | `[v]` Angabe (Reihenfolge 2026-09-27) |
| Bohrbild | **40,5 hoch × 16,5 quer**, 4 × M3 | `[v]` am 2026-09-17 mit Bohrlehre am Modul bestätigt |
| Gehäuse (angenommen) | 35 × 35 mm Querschnitt | `[w]` |

Das Netzteil liefert 24 V, der Laser braucht 12 V: dazwischen sitzt ein
Abwärtswandler — siehe [elektronik.md](elektronik.md#anschlussplan), die
Verdrahtung in [verkabelung.md](verkabelung.md).

Messhistorie an diesem Modul: **39 × 15** (erste Angabe) → **40 × 16**
(`hardware.md`, eigene Messung) → **40,5 × 16,5** — mit `Bohrlehre_Laser`
(Ø3,4 Rundlöcher) am Teil geprüft und bestätigt. Damit war auch belegt, dass
Rundlöcher an dieser Stelle funktionieren — die Schlittenplatte hatte deshalb
in Rev. 12/13 **Rundlöcher Ø4,0**. Seit Rev. 14 sind es **senkrechte
Langlöcher 4,0 × ±8 mm**, aber aus einem anderen Grund: nicht Lochbildtoleranz,
sondern Höhenverstellung für den unbekannten Fokusabstand (unten).

Die Lochbildtoleranz beträgt damit **±1,0 mm je Achse** (Ø4,0 auf Schaft Ø3),
deckt also 39,5 – 41,5 hoch und 15,5 – 17,5 quer ab — die Messung 40 × 16
liegt noch darin, die erste Angabe 39 × 15 nicht mehr. `toolhead_check.py`
führt Toleranz und Messhistorie im Bericht mit. Reicht der Bereich gegen den
Schrumpf nicht, genügt `laser_loch_d` von 4,0 auf 4,5 mm.

Ist das Gehäuse tiefer oder flacher als 35 mm, `laser_tiefe` anpassen — davon
hängt nur die berechnete Lage der Strahlachse ab, nicht die Geometrie.

### Gewindeeinsätze `[v]`

| Wert | Maß | Status |
|---|---|---|
| Typ | Messing-Einschmelzeinsatz M3 | `[v]` |
| Außendurchmesser | **5,0 mm** | `[v]` am Teil |
| Einpressbohrung im Skript | **4,6 mm** × 7 mm tief | `[v]` |
| Wand im Schienensockel | **2,20 mm** je Seite | Minimum aus `hardware.md`: 2,0 |

Nicht die ruthex-Maße aus `references/hardware.md` (M3: OD 4,6 → Bohrung 4,0).
Die Bohrung liegt 0,4 mm unter dem Außendurchmesser, damit der Einsatz beim
Einschmelzen Material verdrängt und greift. Der Schienensockel ist 9 mm breit
und darf es bleiben — damit ist diese Bohrung die engste Stelle im ganzen
Teil.

### Fokusabstand `[?]` — offen

| Wert | Maß | Status |
|---|---|---|
| Fokusabstand f (Gehäuseunterkante → Material) | **unbekannt** | Modul hat einen einstellbaren Fokus, kein festes f |

Das Modul ist ein **LASER TREE 4 W** mit einstellbarem Fokus (Angabe vom
2026-09-25). `hardware.md` führte als Kandidaten das *Laser Tree LT-20W-A*
mit „Fokus einstellbar 20–35 mm" `[w]` — das ist es also nicht, der
Bereich gilt nicht. f steckt deshalb weiter **nicht** in der Geometrie: die
Laserhöhe wird über senkrechte Langlöcher (±8 mm, nach oben nutzbar
+7,8 mm) eingestellt, der Fokus am Modul. Der Validierungsbericht rechnet
die Stellung je f aus.

Selbst messen: Papier aufs Bett, 1–2 % Leistung, Höhe variieren bis der Punkt
am kleinsten ist, dann Gehäuseunterkante → Papier messen. Sobald der Wert
bekannt ist, hier eintragen und auf `[v]` setzen.

## Endschalter

| Wert | Maß | Status |
|---|---|---|
| Typ | Gabellichtschranke LM393 (Hailege) | `[v]` |
| Platine | **25 × 20 mm** | `[v]` gemessen |
| Gabelspalt | **10 mm**, mittig (5 mm vom Platinenrand) | `[v]` |
| Lage der Gabel | 1 mm von der 20-mm-Kante | `[v]` |
| Gabel: Höhe über der Platine | **15 mm** | `[v]` gemessen (a) |
| Gabel: außen, quer zum Schlitz | **18,5 mm** | `[v]` gemessen (b) |
| Gabel: Dicke entlang der Platine | **6 mm** → Strahl **4 mm** über der Stirnkante | `[v]` gemessen (c) |
| Lichtfenster über der Platine | **9 mm** | `[v]` gemessen (d) |
| Boden des Schlitzes über der Platine | 6 mm geschätzt, muss ≤ 6,5 mm sein | `[?]` nicht gemessen |
| Bohrbild | 2 × M3 in den Ecken der Gegenseite, Lochrand 1 mm von beiden Kanten → **Lochmitten 2,5 mm, Abstand 15 mm** | `[v]` gemessen, Lochmitte abgeleitet |
| Versorgung | 3,3 / 5 V, D0 digital | `[w]` |
| Befestigung | 2 × M2×6 in Heat Inserts **M2 Ø3,2 × 2,5** | `[v]` vorhanden |

Einpressbohrung für die M2-Einsätze: **Ø2,8 × 3 mm**, also 0,4 mm unter dem
Außendurchmesser — dieselbe Regel wie bei den M3-Einsätzen am Schienensockel.

Wie es eingebaut ist, am Toolhead gemessen (2026-09-23, noch ohne
Motoradapter, Wagen oben an der Kupplung):

| Wert | Maß | Status |
|---|---|---|
| Konsolenunterseite → Mitte oberer Einsatz des Sockels (C) | **18 mm** → Einsätze bei Z = +127 / +107 | `[v]` |
| Konsolenunterseite → Unterkante Kupplung (D) | **20 mm** | `[v]` |
| Unterkante Platine → Oberkante alte Fahne (B) | **32 mm** → Halter steht ganz oben im Langloch | `[v]` |

Daraus folgt Rev. 32: der Halter bleibt und kommt ganz nach unten, die
angeformte Fahne weicht einer eigenen schwarzen Schaltfahne, die bis an den
Strahl reicht — siehe `toolhead-z.md`, Endschalter.

Ebenfalls vorhanden: **induktiver Näherungsschalter LJ12A3-4-Z/BX** (M12,
Sn 4 mm, NPN Schließer, 6–36 V). Für Z am Toolhead ungeeignet — 60 g,
Pegelwandler nötig, ±0,1…0,2 mm Wiederholgenauigkeit. Für X und Y am Rahmen
war er zuerst vorgesehen; inzwischen sitzen auch dort Gabellichtschranken,
die ohne Optokoppler auskommen — Halter und Fahnen in
[endschalter.md](endschalter.md). Achtung: Schließer meldet bei
Kabelbruch nicht; der Öffner (`/AX`) wäre für Endschalter die sichere
Variante.

## Maschinenmaße für die Z-Achse

| Wert | Maß | Status |
|---|---|---|
| Bezugsebene (Mitte X-Wagen-Lochbild) → Bettoberfläche | **130 mm** | `[?]` am 2026-09-17 genannt, auf cm gerundet |
| dickstes Werkstück | **50 mm** | Vorgabe |

Beide stehen als `bett_abstand` und `werkstueck_max` im Skript — sie erzeugen
keine Geometrie, sondern nur die Fokusrechnung im Bericht. Aus ihnen folgt das
Fenster **f = 6 … 57 mm**, in dem 0–50 mm Werkstückdicke erreichbar bleiben
(oben gerechnet bis zum Schaltpunkt des Endschalters, nicht bis zur
mechanischen Grenze — bis Rev. 28 stand hier fälschlich 49; mit dem
10-mm-Motoradapter und der gemessenen Garnitur von 38 mm sind es seit
Rev. 31 57 mm).
Nach oben begrenzt es die Montage (die obere Laser-Schraubenreihe muss beim
Verschrauben neben dem Z-Wagen liegen, also höchstens +7,8 mm über Lochmitte),
nach unten der Langlochhub von −8 mm. Seit Rev. 27 hängt der Laser dafür 5 mm
tiefer am Schlitten; vorher reichte das Fenster erst ab f = 11 mm.
Mit der 95-mm-Schiene stand hier einmal `f ≤ 27,1 mm` — das war die alte,
kurze Z-Achse.

Eine dickere Opferplatte wirkt wie eine Langlochstellung nach unten (1 mm
dicker = 1 mm tiefer) und verschiebt das Fenster nur in diese Richtung.
Die Spanplatte (25,3 mm) liegt deshalb zwischen Führungsfüßen derselben
Höhe: Ihre Oberfläche liegt auf der Unterkante der 2060, wo vorher der
Tisch war, und Bettabstand und Fenster gelten weiter
([opferplatte.md](opferplatte.md)). Aus den Profilmaßen sind es 129 mm
statt der gerundeten 130.

## Z-Antrieb: Trapezgewindespindel Tr8×2 mit Anti-Backlash-Garnitur `[w]`

**Bestellt** (Spindel + Garnitur + Kupplung), Maße aus den Herstellerbildern
der Angebote — noch nicht am Teil gemessen:

| Wert | Maß | Status |
|---|---|---|
| Spindel | Tr8×2, 1-gängig, Steigung = Vorschub 2 mm, 200 mm lang | `[w]` |
| Ende | kein angedrehter Zapfen — Ø8 ist der Gewindeaußendurchmesser | `[w]` |
| Flanschmutter: Flansch | **Ø22 mm**, Bauhöhe **15 mm** | `[w]` |
| Flanschmutter: Bund Ø10 × 2 mm | auf der **Oberseite**, Flansch unten **glatt** | `[v]` am Teil |
| Flanschmutter: Dicke der Flanschplatte | **3,5 mm** | `[v]` am Teil gemessen |
| Flanschmutter: Lochkreis | **Ø16 mm**, **4 × Ø3,5 durchgehend** (kein Gewinde!) | `[w]` |
| Gleitmutter (zweite Hälfte) | **Ø14 × 15 mm**, mit Mitnehmernut | `[w]` |
| Druckfeder | **Ø12 × 50 mm** freie Länge | `[w]` |
| Garnitur eingebaut (Unterseite Flansch bis Oberkante Gleitmutter) | **38 mm** | `[v]` am Teil gemessen |
| Kupplung | UniTak3D 5 → 8 mm (B096G1GZH5), **starre Klemmkupplung**, seitliche Klemmschrauben | `[w]`, Maße am Teil messen |

Wichtig für den Entwurf: die Befestigungslöcher sind **Durchgangslöcher**, das
Gewinde muss also im Druckteil sitzen — mit den vorhandenen M3-Messingeinsätzen
(Ø4,6 × 7) braucht der Flanschsitz mindestens 9 mm Material. Das Regal des
Mutternwinkels ist deshalb 10 mm dick.

Im Skript steckt das als `spindel_d` 8,0 · `spindel_durchgang` 8,6 ·
`t8_flansch_d` 22 · `t8_lochkreis` 16 · `t8_garnitur_h` 38.

**Zur Kupplung:** weil es kein oberes Spindellager gibt, hängt der Z-Schlitten
(5,6 N) axial an der Kupplung. Damit sind **Oldham- und Klauenkupplungen
ausgeschlossen** — ihre Naben sind nicht axial verbunden, sie setzen Wellen
voraus, die jede für sich gelagert sind. Bleiben die einteiligen: starre
Klemmhülse oder Wendelkupplung. Bestellt ist die UniTak3D 5 × 8, eine
**starre Klemmkupplung** mit seitlichen Klemmschrauben — die beste Bauart für
diese Achse: trägt die Last axial voll und greift rundum auf die
Gewindespitzen. Beide Wellen über den ganzen Klemmbereich einstecken, etwa bis
zur Mitte — Begründung in `toolhead-z.md`.

**Am gelieferten Teil zu prüfen (drei Dinge):**

1. ~~Einbauhöhe der Garnitur~~ **Erledigt** `[v]`: **38 mm** gemessen
   (`t8_garnitur_h`, bis Rev. 30 auf 45 mm geschätzt). Sie bindet den
   Verfahrweg nach oben, der damit 93,6 mm beträgt.
2. ~~Flanschfläche plan?~~ **Erledigt** `[v]`: die Unterseite des Flansches
   ist glatt, der Bund Ø10 × 2 sitzt oben. Die glatte Seite liegt auf dem
   Regal, es braucht keinen Freiraum und keinen Zwischenring (Rev. 25–27 gab
   es einen Flanschring, weil der Bund unten vermutet war). Mit 3,5 mm
   Flanschdicke genügen **M3×8** bei 4,5 mm Eingriff.
3. **Maße der Kupplung**: Länge, Durchmesser, Länge des Klemmschlitzes.
   Daraus folgt `kupplung_griff` (modelliert 8 mm, für diese Kupplung eher 12).
   Der Wert verschiebt die Kupplung in Z und damit den Verfahrweg. Seit dem
   Motoradapter (Rev. 30) kommt die Kupplung ohnehin nur 8 mm auf die
   Motorwelle, sonst rutscht ihre obere Klemmschraube in die Konsole — also
   auch nachsehen, **wo die Klemmschrauben sitzen** (angenommen: Mitte der
   Nabe). Gemessen ist bisher nur ihre Lage ohne Adapter: 20 mm unter der
   Konsole. Bei 24 mm Motorwelle steckt die Spindel darin **höchstens 4 mm**
   tief — beim Einbau des Adapters neu setzen (`toolhead-z.md`, Kupplung).

Und eine Entscheidung, die daraus schon feststeht: **die Spindel wird
gekürzt**, auf `spindel_zuschnitt` = 160 mm (gebraucht 147,6 mm). Ungekürzt
hängt das untere Ende bis Z = −80 und drückt die mögliche Werkstückhöhe von 59
auf 45 mm — unter die geforderten 50.

Steigungswinkel 5,2° am Flankendurchmesser → **selbsthemmend** (TR8×8 mit 20°
wäre es nicht). Betriebsmoment ≈ 70 mNm, davon 64 mNm allein die
Federvorspannung der Garnitur; eine Klemmnabe auf Ø8 trägt ein Mehrfaches,
auch auf Gewindespitzen. Rechnung in `tools/toolhead_check.py`, Abschnitt 7.

## Schrittmotortreiber: A4988 oder TMC? `[w]`

**Empfehlung: TMC2209 — aber nicht wegen des Microsteppings.** Das ist der
verbreitete Denkfehler, und die Zahlen dieser Achse zeigen warum.

### Warum die Auflösung kein Argument ist

| | 1/16 (A4988-Maximum) | 1/256 (TMC) |
|---|---|---|
| Z, Tr8×2 | 1600 Schritte/mm → **0,63 µm** | 25 600/mm → 0,04 µm |
| X/Y, GT2-20T (40 mm/U, angenommen) | 80 Schritte/mm → **12,5 µm** | 1280/mm → 0,8 µm |

Zwei Gründe, warum das untere Ende dieser Tabelle nichts bringt:

1. **Reibungstotzone.** Der Rotor rückt erst weiter, wenn das Moment die
   Reibung überwindet: `T = T_halt · sin(el. Winkel)`, 90 el. Grad = ein
   Vollschritt = 1,8 mech. Grad. Bei 70 mNm Reibung (davon 64 mNm allein die
   Federvorspannung der Anti-Backlash-Garnitur) gegen 400 mNm Haltemoment sind
   das 0,20 mech. Grad, also **1,1 µm Totzone** in Z. Ein 1/16-Mikroschritt ist
   mit 0,63 µm schon feiner als das, was die Achse überhaupt auflösen kann.
   `toolhead_check.py` Abschnitt 7 rechnet beide Werte mit.
2. **Schrittrate.** 1/256 extern ist bei Gravurgeschwindigkeit nicht
   übertragbar: 300 mm/s auf X wären bei 1/16 schon 24 kHz Schrittrate (nahe
   am Limit eines 8-Bit-GRBL), bei 1/256 rechnerisch 384 kHz. Deshalb
   **interpoliert** der TMC intern (MicroPlyer): man füttert ihn mit 1/16 und
   bekommt die Laufruhe von 1/256, ohne Schrittrate zu bezahlen. Das ist der
   eigentliche Nutzen — Laufruhe, nicht Genauigkeit.

### Was der TMC wirklich bringt

* **Leise.** StealthChop2 arbeitet oberhalb des Hörbereichs. Bei
  Gravurjobs über Stunden ist das der praktisch größte Unterschied.
* **Kühler und sauberer geregelt.** Weniger Stromwelligkeit heißt weniger
  Motorerwärmung und weniger Resonanz — Resonanz zeigt sich in der Gravur als
  Streifen.
* **Strom per UART setzen** (TMC2209) statt Vref-Poti abgleichen; dazu
  Diagnose (Übertemperatur, Leitungsbruch) und CoolStep.
* StallGuard4 könnte sensorlos referenzieren — brauchen wir nicht, die
  Z-Achse hat die Gabellichtschranke.

Dagegen der A4988: **billiger** (~1,50 € gegen 4–6 €), robust, nichts zu
konfigurieren, und er verträgt bis 35 V. Für 3 Achsen ist der Aufpreis rund
15 € — gegenüber Spindel plus Garnitur belanglos.

| | A4988 | DRV8825 | TMC2209 |
|---|---|---|---|
| Preis | ~1,50 € | ~2 € | 4–6 € |
| Versorgung | 8–35 V | 8,2–45 V | ~5–28 V (abs. max 29) |
| Strom | bis 2 A/Phase (IC), ohne Kühlung real ~1 A | ohne Kühlkörper ~1,5 A, mit Kühlung bis 2,2 A | bis 2 A RMS (IC), Modul je nach Kühlkörper ~1,2–1,4 A |
| Microstepping | max. 1/16 | max. 1/32 | 8/16/32/64 extern, intern auf 1/256 interpoliert |
| Geräusch | laut | laut | leise (StealthChop) |
| Konfiguration | Jumper + Vref-Poti | Jumper + Vref-Poti | Jumper oder UART |

Bei 24 V passen alle drei. Über 29 V fällt der TMC2209 aus (dann TMC2130/5160
oder DRV8825). Nur wenn die Motoren 2-A-Typen sind, wird es am 2209-Modul eng.

### Und der DRV8825?

Steckt ohne Umbau im Sockel des A4988 und kann mehr: ~1,5 A ohne
Kühlkörper, 1/32, bis 45 V. Bei 24 V und Motoren um 1 A bringt das an dieser
Maschine nichts. Dafür hat er eine bekannte Schwäche: sehr kleine
Spulenströme, wie sie nahe dem Nulldurchgang der Sinuskurve gebraucht werden,
regelt er wegen seiner Mindest-Einschaltzeit nicht sauber — besonders bei
24 V und Motoren mit kleiner Induktivität. Die Mikroschritte werden dann bei
langsamer Fahrt ungleichmäßig. Am 3D-Drucker zeigt sich das als feine
Streifen („Lachshaut“), Abhilfe dort sind Diodenmodule (TL-Smoother) zwischen
Treiber und Motor. Beim Laser trifft es am ehesten Graustufen-Raster; die
Fehler liegen im Bereich von Hundertsteln Millimetern, bei Linien und
Füllungen fällt das kaum auf.

Fallen beim Einbau:

* **1/16 ist nur der MS3-Jumper** (M2), alle drei Jumper ergeben 1/32 —
  anders als beim A4988.
* Strom: **I = 2 × Vref** (Module mit 0,1-Ω-Messwiderständen, die üblichen).
  Beispiel: 1,5-A-Motor, davon 70 % → 1,05 A → Vref ≈ 0,53 V.
* Das Poti sitzt am anderen Ende als beim A4988 — nach dem EN-Pin ausrichten.
* Der GRBL-Standard `$0=10` (µs Schrittpuls) passt, der DRV8825 braucht
  ≥ 1,9 µs.

Fazit: taugt als billige Alternative zum A4988, die Empfehlung bleibt der
TMC2209. **Entschieden (2026-09-25): TMC2209.**

### Fallstricke, falls es TMC wird

* **Nicht mitten in der Bewegung zwischen StealthChop und SpreadCycle
  umschalten** (`TPWMTHRS`): der Sprung ist beim Laser als Linie sichtbar. Für
  X/Y einen Modus über den ganzen Geschwindigkeitsbereich wählen — SpreadCycle,
  wenn schnell gefahren wird. Für Z ist StealthChop unkritisch, die Achse
  fährt nur zwischen den Jobs.
* **Drehrichtung.** In einem A4988-Sockel läuft ein TMC-Modul
  spiegelbildlich (DIR-Logik), also Stecker drehen oder in der Firmware
  invertieren.
* Standalone-Betrieb kann StealthChop bei hoher Beschleunigung Schritte
  verlieren — mit UART ist das einstellbar, ohne nicht.

Board: geplant ist ein **Arduino Uno R3 mit CNC Shield V3** (siehe
[Elektronik](#elektronik)) — damit bleibt es beim Standalone-Modus mit Jumpern.
Nur mit UART-Anbindung (SKR/Octopus, FluidNC am ESP32 o. ä.) wären Strom und
Chopper einstellbar.

## Elektronik

**Stand 2026-09-27:** Arduino Uno R3 und CNC Shield V3 vorhanden, Treiber:
**5 × TMC2209** (GERUI TMC2209 V2.0 mit Kühlkörper; 4 + 1 Ersatz),
Steckernetzteil 24 V / 3 A, Laser 12 V / 1,6 A über einen Abwärtswandler
12 V / 5 A (43 × 24 × 20 mm). Vier NEMA 17 **Stepperonline 17HE15-1504S**
(1,5 A) — genau die vier Treiberplätze des Shields. Pinbelegung
und Jumper `[w]` (GRBL 1.1, Shield V3 und seine Nachbauten). Wo Steuerung,
Netzteil, Endschalter und Kabel hinkommen, und das Gehäuse
(`fusion/Elektronik`): [elektronik.md](elektronik.md). Hohlstecker des
Netzteils: **5,5 × 2,1 mm** `[v]` Angabe; Lüfter 24 V. Not-Aus: Pilztaster
„STOP“, rastet, Drehen löst, **ein Wechsler C/NO/NC** mit Lötfahnen `[v]`
(Bild 2026-09-30), **3 A / 250 V**, Gewinde **16 mm** rund `[v]` Angabe —
Gehäuse und Verdrahtung in [notaus.md](notaus.md). Abwärtswandler 24 → 5 V
für den Pi: **63 × 30 mm**, höchstens 20 mm hoch, Schraubklemmen und
USB-A-Buchse an den schmalen Seiten `[v]` Angabe (2026-10-10) — Halter in
[pi.md](pi.md#halter).

| Steckplatz | Motor | Schritte/mm bei 1/16 |
|---|---|---|
| X | X-Motor | `$100=80` (GT2, 20 Z: 40 mm je Umdrehung) |
| Y | Y-Motor der einen Ecke | `$101=80` (GT2, 20 Z direkt auf der Welle) |
| A | Y-Motor der anderen Ecke, **Klon von Y**: Jumper A.STEP↔Y.STEP und A.DIR↔Y.DIR | folgt Y |
| Z | Z-Motor | `$102=1600` (Tr8×2) |

GRBL 1.1h mit der Arduino-IDE aufspielen (Bibliothek `grbl`, Beispiel
`grblUpload`). GRBL auf dem Uno kennt nur X, Y und Z — A ist deshalb keine
eigene Achse, sondern eine elektrische Kopie von Y.

### Zwei Y-Motoren

* **Drehrichtung im Kabel umkehren.** Die Ritzel vorn drehen gegenläufig, Y und
  A bekommen aber dasselbe DIR-Signal. `$3` hilft nicht, es dreht Y und A
  gemeinsam um. Also am zweiten Y-Motor die zwei Adern **einer** Spule
  tauschen (oder den Stecker um 180° drehen). Prüfen, bevor das Portal an
  beiden Riemen hängt: bei gleich eingebauten Motoren drehen die Motorwellen,
  von oben gesehen, gegenläufig.
* **Gleiche Treiber auf Y und A**, gleiche Mikroschritt-Jumper, gleicher
  Strom. Mischbestückung ändert den Drehsinn einer Seite (ein TMC läuft
  gegenüber einem A4988 spiegelbildlich, siehe oben) und womöglich ihre
  Schrittweite.
* **Kein Auto-Squaring.** Mit geklontem A kann GRBL die Seiten nicht getrennt
  referenzieren; ein Y-Endschalter auf einer Seite genügt. Rohr und Schlitten
  sitzen starr auf den Wagen, die Rechtwinkligkeit legen also die Teile fest
  (prüfen wie in [ausrichten.md](ausrichten.md)) — die Motoren dürfen nur nicht
  gegeneinander ziehen. Einmal einstellen: an einer Ecke die Madenschrauben
  des Ritzels auf der Motorwelle lösen, Portal von Hand durchschieben, bis es frei läuft,
  festziehen. Nach einem Schrittverlust auf einer Seite dasselbe.

### Pins: GRBL 1.1 gegen den Aufdruck

Der Aufdruck des Shields stammt aus GRBL 0.9. In GRBL 1.1 braucht die
Laserleistung den Hardware-PWM an D11, dafür ist der Z-Endschalter auf D12
gewandert:

| Aufdruck | Uno-Pin | GRBL 1.1 |
|---|---|---|
| X+ / X− | D9 | Endschalter X |
| Y+ / Y− | D10 | Endschalter Y (nur eine Seite) |
| **Z+ / Z−** | D11 | **Laser-PWM** — kein Endschalter! |
| **SpnEn** | D12 | **Endschalter Z** (Gabellichtschranke) |
| SpnDir | D13 | Spindelrichtung, für den Laser frei |
| Abort | A0 | 24-V-Wächter: fehlen die 24 V, bricht GRBL ab ([verkabelung.md](verkabelung.md#7-24-v-wächter-w16)) |

* Laser: PWM (5 V TTL) an den PWM-Eingang des Lasertreibers, Masse gemeinsam
  mit dem Shield. `$32=1` (Lasermodus), `$30=1000` passend zum S-Maximum der
  Gravursoftware.
* Endschalter: die Gabellichtschranke (LM393, 5 V) geht direkt. Die
  induktiven LJ12A3 (6–36 V) nicht direkt an die 5-V-Eingänge —
  Optokoppler davor.
* Belegung im Einzelnen (X an X−, Y an Y+, Z an SpnEn, 5 V und GND der
  Lichtschranken über die Wagos, Pull-down 10 kΩ auf Z−):
  [verkabelung.md](verkabelung.md#klemmen-wago-und-shield).

### Treiber und Versorgung

* Das Shield führt keine UART-Leitung, TMC2209 laufen also standalone:
  **MS1 + MS2 stecken = 1/16** (intern auf 1/256 interpoliert), MS3 frei. Beim
  A4988 alle drei Jumper = 1/16, beim **DRV8825 nur MS3 = 1/16** (alle drei =
  1/32, dann `$100=$101=160`, `$102=3200` und Z höchstens ~500 mm/min, weil
  der Uno bei ~30 kHz Schluss macht). Strom über das Vref-Poti nach der Formel
  des Moduls (hängt vom Messwiderstand ab), etwa 70 % des Motornennstroms.
* **Vref der GERUI TMC2209 V2.0:** Ohne UART stellt das Poti den
  Effektivstrom ein: I_eff = 0,325 V / (R_sense + 0,02 Ω) / √2 × Vref / 2,5 V
  (TMC2209-Datenblatt) `[w]`. R_sense hängt vom Modul ab — üblich sind
  0,11 Ω (Aufdruck **R110**), bei manchen 0,10 oder 0,15 Ω. Auf den GERUI
  ist kein R110 zu finden (Angabe 2026-09-27). Ziel: 70 % von 1,5 A =
  **1,05 A eff.**:

  | Messwiderstand | Vref für 1,05 A | mit 1,37 V fließen |
  |---|---|---|
  | R100 (0,10 Ω) | **1,37 V** | 1,05 A |
  | R110 (0,11 Ω) | 1,48 V | 0,97 A |
  | R150 (0,15 Ω) | 1,94 V | 0,74 A |

  Solange der Wert unbekannt ist, **mit 1,37 V anfangen** — das sind bei
  jedem der drei höchstens 1,05 A. Die Aufschrift sitzt auf den zwei
  kleinen Widerständen neben dem Chip — je nach Modul oben oder auf der
  Unterseite. Messen zwischen GND und dem Schleifer des Potis (Shield an
  24 V, Uno an USB, Motoren dürfen ab sein), mit einem isolierten
  Schraubendreher drehen. Werden die Motoren über 70 °C heiß, zurück; laufen
  sie kalt und verlieren Schritte, höchstens bis 1,2 A (R100: 1,57 V,
  R110: 1,70 V, R150: 2,22 V) — das Netzteil trägt das noch (≈ 59 W statt
  53 W). Alle vier gleich einstellen, Y und A auf jeden Fall.
* Treiber richtig herum stecken (EN-Pin zum EN-Aufdruck) und Motoren nie unter
  Spannung ab- oder anstecken — beides kostet den Treiber.
* Netzteil 24 V für die Motoren (TMC2209 abs. max 29 V, siehe oben). Der Laser
  nach seinem Typenschild; ist er ein 12-V-Modul, bekommt er einen eigenen
  12-V-Zweig. **Vorhanden: Steckernetzteil GIDEALED 24 V / 3 A (72 W)**
  `[v]` Angabe. Motoren ≈ 23 W, Lüfter ≈ 2 W, Laser mit Wandler ≈ 24 W,
  [Pi](pi.md) mit Uno und Lichtschranken über seinen 5-V-Wandler ≈ 4 W —
  zusammen ≈ 53 W, dauernd gehen 61 W. Bilanz in
  [elektronik.md](elektronik.md#leistung-reichen-72-w).

### Grenzen des Uno

8-Bit-GRBL schafft etwa 30 kHz Schrittrate — bei 80 Schritten/mm 375 mm/s,
mehr als ein Diodenlaser braucht. Der Engpass ist die serielle Übertragung:
Graustufenbilder schnell zu rastern kann stocken. Daran ändert der
[Pi](pi.md) nichts, er schickt die Datei über dieselbe serielle Leitung. Für
Linien und Füllungen reicht es; wer später schneller rastern will, wechselt
auf ein 32-Bit-Board (ESP32 mit FluidNC o. ä.) — die Mechanik bleibt gleich.

## Y-Antrieb

Nutzerangaben vom 2026-09-26 mit Foto, Halter seit Portal Rev. 16 in
`fusion/Portal/Portal.py` (bis Rev. 15 `fusion/YMotorhalter/`, Rev. 5), Doku
in `y-motorhalter.md`. Portal und Rahmen siehe
[Y-Achse und Portal](#y-achse-und-portal).

| Wert | Maß | Status |
|---|---|---|
| Y-Profil | **2040 hochkant**, liegt vorn auf dem vorderen 2060, das **35 mm** hinter der Stirnseite sitzt; dort halten **Winkel** die 2040 an ihren Seitenflächen, davor sind die Seitenflächen frei; vor und unter dem Profilende ist Platz | Nutzerangabe (Winkel 2026-09-27), 2060 `[v]` |
| Nuten | je Seitenfläche zwei, 10 mm über der Unter- und unter der Oberkante; in den **oberen** läuft der Y-Riemen, **in der rechten hin, in der linken zurück**; in die **unteren** kommen die Nutensteine | Nutzerangabe, Lage `[w]` |
| Nut 6 | Öffnung 6,2, Lippe 1,8, Platz bis zum Nutgrund 6,0 | `[w]` |
| Motoren | **2 × NEMA 17**, je Seite einer vorn am Profilende, Welle nach oben, Achse mittig zur 2040 | Nutzerangabe |
| Ritzel | **GT2 20 Z, Bohrung 5**, direkt auf der Motorwelle | Nutzerangabe |
| Trume in der Nut | 12,73 mm auseinander (20 Z): Rücken 3,26, Zahnspitzen 4,64 mm hinter der Seitenfläche | gerechnet aus Nut 6 `[w]` |
| Motorwelle | **23 mm** ab Flansch (60 mm mit, 37 mm ohne Welle), Abflachung 15 mm ab Wellenende angenommen — der 17HE15-1504S hat 20 mm, die Madenschraube trifft also sicher | `[v]` Länge, Abflachung `[w]` |
| Y-Motor | Körper **37 mm**, hängt bis 25,5 mm unter die 2040 | `[v]` |
| Nutensteine M5, Nut 6 | Lippe 1,8, Gewinde 4, Platz in der Nut 6 mm → M5×12 + Scheibe | `[w]` |
| gedruckter Halter (Portal.py bis Rev. 15) | Motorachse 15,55 mm neben der Profilmitte, M5 in der oberen Nut — daher Rev. 3 | Nutzerangabe, Foto |

**Rev. 1/2 beruhten auf einem Missverständnis:** ein Motor mittig an der
hinteren Traverse, der über einen Omega-Riemen zwei senkrechte
Edelstahlwellen treibt. Die Werte dazu (Wellen Ø5 in 625ZZ, Wellenabstand,
Motorriemen, Umlenkrollen aus F625ZZ) gelten für den Y-Antrieb nicht mehr.

**Drehrichtung:** Beide Motoren sind gleich eingebaut, die Y-Riemen liegen
aber spiegelbildlich: Die Motoren müssen gegenläufig drehen. Am CNC Shield
bekommt der zweite Y-Motor (A, Klon von Y) dasselbe DIR-Signal, deshalb an
ihm eine Spule tauschen — siehe [Zwei Y-Motoren](#zwei-y-motoren).

## Energieketten

Angabe vom 2026-10-01: Die Ketten werden **selbst gedruckt**, für X und Y.
Gedruckt ist bisher eine, die zweite kommt in derselben Größe. Die Maße
stammen aus deiner 3MF, der Anschlag vom gedruckten Teil. Wannen,
Festpunkte und Kettenhalter beider Ketten und der Kabelweg zwischen ihnen
stehen in [energiekette.md](energiekette.md).

| Wert | Maß | Status |
|---|---|---|
| Modell | „Energiekette“ von lingnau.florian (CC BY-NC-SA): Kettenglied mit Riegel, Anfangsstück, Endstück, Endstück 180, Drehkonsole | Angabe 2026-10-01, 3MF |
| Glied | Teilung **16**, außen **18 × 14** (der Riegel steht 0,3 über), innen **10 × 8,8**, 30 lang | aus dem Modell gemessen |
| Gelenk | Zapfen Ø5,0 im Loch Ø5,4, mittig in der Höhe; rückwärts 0° | aus dem Modell gemessen |
| Anschlag | im Modell **47°** je Gelenk; am gedruckten Teil knicken im 180°-Bogen **4 Gelenke** (je etwa 45°). Die Angabe 30° vom 2026-10-01 war zu klein | gezählt 2026-10-02 |
| Schleife | um 180° gebogen außen **50 mm** (Messschieber) | gemessen 2026-10-02 |
| Biegeradius | bei 47° 20,1 mm auf der Gelenklinie, gerechnet **R 20**: Schleife 54,6 mm, nie enger als gemessen | gerechnet (Portal.py Rev. 22, ToolheadZ.py Rev. 37; Rev. 20/21: R 32) |
| Riegelseite | nur durch einzelne Streben geschlossen, die Litzen lassen sich jederzeit einlegen und herausnehmen | Angabe 2026-10-01 |
| Anschlussstücke | 43 lang: 36 hinter dem Gelenk, Auge 7; Platte 2 mm mit 2 × Ø5,5, 18 und 30 mm hinter dem Gelenk | aus dem Modell gemessen |
| X-Kette | 17 Glieder, 344 mm mit Anfangsstück und Endstück 180 | gerechnet (Portal.py Rev. 22) |
| Y-Kette | 16 Glieder, 328 mm, gleiche Größe wie X: Arbeitsweg plus 47 mm Reserve nach vorn (gewählt: mindestens 26) | gerechnet (Portal.py Rev. 22), Wahl 2026-10-01 |
| Linker Y-Schlitten | schon gedruckt: Löcher für den Kettenhalter Y mit der Bohrlehre nachbohren; ein Neudruck hat sie im Modell | Angabe 2026-10-02 |
| Spiel der Kette | 0,5 mm je Seite in Wannen und Kettenhaltern (vorher 0,3) | Wahl 2026-10-02, Portal.py Rev. 23, ToolheadZ.py Rev. 38 |
| Kabelweg zur X-Kette | in der oberen Nut des Portalrohrs, am Festpunkt ein Kabelflügel mit zwei Kabelbindern | Wahl 2026-10-01, Portal.py Rev. 21 |
| Motorkabel (mitgeliefert) | lose Adern in einem Schlauch; in den Ketten ohne Schlauch | Angabe 2026-10-01 |
| Untere Nut an der Unterseite des linken 2040 | belegt: die Wanne Y hängt deshalb an der unteren Seitennut außen | Angabe 2026-10-01 |
| Winkel an den Kreuzungen 2040/2060 | 20 mm, in der unteren Seitennut der 2040 direkt am 2060; sonst sitzt dort zwischen den 2060 nichts | Angaben 2026-09-27/29, bestätigt 2026-10-02 |
| gekaufte Ketten | 10 × 20 mm innen, 15 × 27 mm außen, je 1 m | `[v]` vorhanden, werden nicht verwendet |

## Normteile (aus hardware.md, `[w]`)

| Gewinde | Durchgang | Kopf-Ø | Kopfhöhe |
|---|---|---|---|
| M3 | 3,4 | 5,5 | 3,0 |

Scheiben M3: DIN 125 Ø 7 × 0,5 am Laser (Langloch 4,0 breit, 1,5 mm Auflage je
Seite) · DIN 9021 Ø 9 × 0,8 am schwimmenden Mutternwinkel (deckt dort das
Übermaß Ø4,6).

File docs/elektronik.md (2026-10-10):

# Elektronik — Platz, Gehäuse, Endschalter, Kabel

Wohin mit Steuerung, Netzteil, Endschaltern und Kabeln. Der Platz ist
gerechnet: `python3 tools/portal_check.py`, Abschnitt 16. Das
[Gehäuse](#gehäuse-elektronikpy) erzeugt `fusion/Elektronik/Elektronik.py`,
geprüft mit `python3 tools/elektronik_check.py`. Die Zeichnung erzeugt
`python3 tools/elektronik_zeichnen.py`; sie gibt auch die Kabellängen und
die Spannungsfälle der [Litzen](#litzen) aus;
die [Draufsicht auf das Gehäuse](#gehäuse-elektronikpy)
`python3 tools/elektronik_box_zeichnen.py`, den
[Anschlussplan](#anschlussplan)
`python3 tools/anschluss_zeichnen.py`. **Stand:** Gehäuse gezeichnet
und gedruckt, der Deckel seit Rev. 3 eine höhere Haube (Elektronik.py
Rev. 3, der Kasten wie Rev. 2, mit den Angaben vom Aufbau vom 2026-09-27:
Stapelhöhe, Wandler 12 V / 5 A, Wago-Bestand, 110 mm Überstand der 2040
hinten, Laseranschluss); die Endschalter sind gebaut
([endschalter.md](endschalter.md)). Die Energieketten sind gedruckt, beide
mit Wanne, Festpunkt und Halter, dazu der Kabelweg zwischen ihnen
([energiekette.md](energiekette.md)). **Die ganze Verdrahtung** — Kabelliste,
Anschlussliste, Klemmen, Schritt für Schritt und Inbetriebnahme — steht in
[verkabelung.md](verkabelung.md). Pinbelegung, Treiber und Jumper stehen in
[hardware-notizen.md, Elektronik](hardware-notizen.md#elektronik). Ohne PC
bedient wird die Maschine über einen Pi mit CNCjs ([pi.md](pi.md)), auf
einem eigenen Halter mit Haube rechts neben dem Gehäuse.

Platz für die Elektronik

## Wohin: das Fach hinter dem hinteren 2060

Hinter dem hinteren 2060 stehen die 2040 frei nach hinten über. Darunter,
zwischen Tisch und 2040, fährt nichts hin:

| | |
|---|---|
| Fach | **488 × 104 × 55 mm** (Breite × Tiefe × Höhe) |
| Lage | zwischen den Innenseiten der 2040, von 3 mm hinter dem 2060 bis 3 mm vor ihr hinteres Ende, von 2 mm über dem Tisch bis 3 mm unter die 2040 |
| engste Stelle | **25 mm**: der hintere linke Klemmturm des Y-Schlittens über dem Fach, wenn das Portal am hinteren Schienenende steht (bis Portal Rev. 24: 23 mm) |
| höher geht es | in der Mitte (\|X\| ≤ 225 mm) gleich hinter dem 2060 bis 10 mm über die Oberkante der 2040 (108 mm über dem Fachboden) |

Nach hinten begrenzt das **Schienenende** den Y-Weg, nicht das 2060: Dort
steht der Toolhead mit Z unten noch 26 mm vor dem hinteren 2060, die
Trägerplatte 23 mm vor der Montageplatte. Die Prüfung fährt Portal und
Toolhead über den ganzen Y-Weg bis an das Schienenende, dazu über X und Z,
und lässt nur Stellungen gelten, in denen der Toolhead kein 2060
durchdringt.

Die Tiefe folgt aus dem Überstand der 2040 hinter dem hinteren 2060:
**110 mm** `[v]` (bis Rev. 1 waren 145 mm angenommen), die 2060 liegen damit
**435 mm** Mitte zu Mitte auseinander. Kasten, Kabelkanal und Montageplatte
brauchen 107 mm ab der Rückseite des 2060 und enden 3,4 mm vor dem Ende der
2040 — dafür ist der Kanal 11 statt 12 mm breit.

## Was hinein kommt

| Teil | Platz | Stand |
|---|---|---|
| Steuerung: Uno R3 + CNC Shield V3 + 4 × TMC2209 | im [Gehäuse](#gehäuse-elektronikpy) links, 24-V-Lüfter im Deckel über den Treibern; USB nach hinten zum Pi | gezeichnet |
| Netzteil | **Steckernetzteil GIDEALED 24 V / 3 A (72 W)**, steht außerhalb — ins Gehäuse kommt nur seine 24-V-Leitung | vorhanden |
| 24-V-Eingang | hinten am Gehäuse: Einbaubuchse 5,5 × 2,1 mm (M8) und runder Wippschalter (Blende Ø22,5); an der Buchse zweigt vor dem Schalter W18 zum Pi ab | gezeichnet |
| Verteiler | im Gehäuse rechts: Abwärtswandler 24 → 12 V / 5 A für den Laser (43 × 24 × 20 mm), davor drei Wago-Klemmen: +5 V für die Lichtschranken (221-420, vom 5-V-Stift des Uno), GND (221-420), +24 V (221-415) | gezeichnet, Wandler und Wago vorhanden |
| Not-Aus | vorn am vorderen 2060 im eigenen Gehäuse ([notaus.md](notaus.md)); Pilztaster mit Wechsler, C–NC in der 24-V-Leitung — schaltet Laser und Motoren ab, der 24-V-Wächter meldet es an GRBL | vorhanden, Gehäuse gezeichnet |
| Pi: Raspberry Pi Zero 2 W mit CNCjs, 5-V-Wandler 24 → 5 V | auf dem [Pi-Halter](pi.md#halter) rechts neben dem Gehäuse, obere Nut des hinteren 2060, unter einer [Haube](pi.md#haube); hängt vor Schalter und Not-Aus an der Buchse und versorgt über USB den Uno | Halter und Haube gezeichnet |

Das Gehäuse hängt an der **Rückseite des hinteren 2060** (untere und obere
Nut) mit 4 × M5 in Hammermuttern, wie die übrigen Halter — der Tisch trägt
nichts, die Maschine steht weiter nur auf den 2060.

## Gehäuse (Elektronik.py)

Elektronik-Gehäuse von oben

| Teil | Druck (PETG) | Masse (voll) | Bauraum |
|---|---|---|---|
| Gehäuse mit Montageplatte (Rev. 4) | auf dem Boden stehend | 150 cm³ ≈ 190 g | 202 × 107 × 55 mm |
| Deckel als Haube (Rev. 3) | Oberseite nach unten | 75 cm³ ≈ 96 g | 175 × 91 × 30,5 mm |
| Bohrlehre_Uno (PLA, ausgeblendet) | flach | 7 cm³ ≈ 9 g | 53 × 69 × 2 mm |

Die Massen sind aus den Schritten des Skripts nachgerechnet (Raster,
0,2 mm); maßgeblich ist der erste Lauf in Fusion. Der Kasten war mit
Rev. 2 gedruckt. Rev. 3 hat den Deckel zur [Haube](#deckel-als-haube-rev-3)
gemacht. Rev. 4 gibt dem Kasten ein rundes Loch für den Schalter, dafür
wird er neu gedruckt; sonst ist er gleich geblieben, die Haube passt.
Fertige STL in Drucklage: [`stl/Elektronik_Gehaeuse_r4.stl`](../stl/Elektronik_Gehaeuse_r4.stl)
und [`stl/Elektronik_Deckel_r4.stl`](../stl/Elektronik_Deckel_r4.stl)
(`python3 tools/stl_export.py`, braucht `pip install manifold3d`). Keine Stützen,
4 Wandlinien, ≥ 30 % Infill. Die Oberkante des USB-Fensters ist eine
48-mm-Brücke.

**Aufbau:** Kasten 160 × 91 × 44 mm, 16 mm hinter dem 2060. Die
Montageplatte liegt am 2060 an und trägt den Kasten über den Kanalboden und
drei niedrige Rippen; der Spalt dazwischen (11 mm) ist der **Kabelkanal**
nach rechts. Links im Kasten der Uno auf vier Stehbolzen, die Buchsenkante
hinten am **USB-Fenster**, dort steckt W17 vom Pi. Rechts der Verteiler:
hinten **Einbaubuchse** und **Schalter**, davor der **Wandler** (12 V / 5 A,
43 × 24 × 20 mm) quer,
mittig vor dem Schalter, mit zwei Kabelbindern 15 mm neben seiner Mitte —
sie laufen durch Schlitze im Boden, zwischen Buchse und Schalter bzw.
rechts am Schalter vorbei, und liegen 4 mm innerhalb seiner Enden. Links
und rechts vom Wandler bleiben 22,5 bzw. 28,5 mm für die Drähte. Davor die
drei **Wago-Klemmen** nebeneinander (Klebeband), von links: **+5 V**
(221-420, neben dem Uno), **GND** (221-420), **+24 V** (221-415, beim
Schalter); zusammen 89,8 mm auf 92 mm Platz. Kabelausschnitte oben offen:
links zur Y-Kette und zum linken Y-Motor, vorn in den Kanal.
Lüftungsschlitze rechts oben. Der Deckel ist seit Rev. 3 eine **Haube**:
Er sitzt mit einer Lippe innen an den Wänden und 4 × M3 in Domen außen an
den Seitenwänden, seine Platte liegt aber 25 mm höher. Der **Lüfter** steht
obenauf über der Mitte des Uno und bläst auf die Treiber.

**Warum es passt:** Der Kasten bleibt im Fach. Haube und Lüfter ragen
darüber hinaus, bis 26 mm über die Oberkante des Fachs. Sie stehen aber
16 mm hinter dem 2060 und in der Mitte, dort fährt nichts so tief
herunter. `tools/elektronik_check.py` fährt Portal und Toolhead über den
ganzen Weg dagegen. Die engste Stelle ist 22,7 mm (Montageplatte ↔
Trägerplatte, Portal am hinteren Schienenende). Die Haube bleibt 24,5 mm
vom hinteren linken Klemmturm weg.

### Deckel als Haube (Rev. 3)

Der flache Deckel von Rev. 2 lag 8 mm über den Kühlkörpern, das war zu
flach (Angabe 2026-10-08). Der Kasten war schon gedruckt und blieb, wie
er war. `elektronik_check.py` prüft das Maß für Maß gegen Rev. 2, bis auf
das Schalterloch aus Rev. 4. Neu gedruckt wurde nur der Deckel:

| | |
|---|---|
| Wände | 2,5 mm, stehen auf den Wänden des Kastens und heben die Platte um **25 mm** (`deckel_aufbau`). Unter der Platte sind es jetzt **33 mm** bis zu den Kühlkörpern statt 8 |
| Lippe | wie bisher innen an den Wänden des Kastens, 3 mm tief, 0,3 mm Spiel. Ein Ring innen am Fuß der Haube trägt sie |
| Schrauben | dieselben **4 × M3×8** in die Einsätze der Dome. Über jedem Dom steht eine Säule (Ø11) mit einem Kanal (Ø6,5) von oben, unten bleibt ein 3 mm Boden. Kopf und Inbus 2,5 gehen durch den Kanal bis auf diesen Boden, die Schraube greift 5 mm in den Einsatz |
| Lüfter | oben auf der Platte über der Mitte des Uno, wie bisher 4 × M3×16 mit Mutter |
| Druck | Oberseite aufs Bett, 30,5 mm hoch, keine Stützen. Die Böden über den Domen sind kurze Brücken über den Kanal. Fertig in Drucklage: [`stl/Elektronik_Deckel_r4.stl`](../stl/Elektronik_Deckel_r4.stl), seit Rev. 3 unverändert |

Höher ginge es bis etwa **65 mm** (`deckel_aufbau`), dann käme das
Portalrohr am hinteren Schienenende bis auf 3 mm an die Haube. Mit
`deckel_aufbau = 0` baut das Skript wieder den flachen Deckel.

**Montage:**

1. **Bohrlehre_Uno** drucken und den Uno darauflegen: Alle vier Löcher
   müssen fluchten. Erst dann das Gehäuse drucken.
2. 4 Messing-Einsätze M3 von oben in die Dome.
3. Uno mit 4 × M3×8 auf die Stehbolzen (Kernloch 2,8, die Schraube schneidet
   ihr Gewinde) — **bevor das Shield aufgesteckt wird**, danach liegt es über
   den Schrauben.
4. Shield aufstecken, Treiber (EN-Pin zum EN-Aufdruck), Jumper.
5. Einbaubuchse (Mutter innen) und Schalter (rastet ein) hinten einsetzen.
6. Wandler mit 2 Kabelbindern 2,5 × 200 (die Schlaufe um Boden und Wandler
   ist 105 mm lang), Wago-Klemmen mit Klebeband; verdrahten nach
   [verkabelung.md](verkabelung.md#schritt-für-schritt). Den Wandler
   **ohne Laser** auf 12,0 V stellen.
7. 4 Hammermuttern in die untere und obere Nut der Rückseite des hinteren
   2060, Gehäuse ansetzen, 4 × M5×12. Der Inbus kommt von hinten neben dem
   Kasten vorbei.
8. Kabel links durch den Ausschnitt; die für rechts vorn in den Kanal und
   darin nach rechts.
9. Lüfter mit 4 × M3×16 und Muttern auf die Haube, **blasend nach unten**
   (Pfeil am Lüfterrahmen), Kabel durch die Öffnung. Haube aufsetzen, die
   Lippe innen an den Wänden, 4 × M3×8 von oben durch die Kanäle der
   Säulen. Dafür einen langen Inbus 2,5 nehmen, der Kanal ist 25 mm tief.

**Gemessen `[v]` (2026-09-27):** die Höhe von Uno, Shield und Treibern mit
Kühlkörper, **28 mm** ab Unterseite Uno (bis Rev. 1 mit 34 mm angenommen) —
der Kasten endet 8 mm darüber und ist dadurch 6 mm niedriger (die Platte
der Haube liegt seit Rev. 3 33 mm darüber); das
Lochbild des Uno stimmt mit der Bohrlehre; der Wandler, 43 × 24 × 20 mm.

**Schalter (Rev. 4):** rund, die Blende außen **22,5 mm** `[v]` (Angabe
2026-10-09; bis Rev. 3 war ein eckiger KCD1 mit 19,2 × 12,9 angenommen).
Das Einbauloch ist **Ø20,2** angenommen `[?]`, bei dieser Blende üblich
20 mm. Die Wand ist um das Loch innen auf 1,6 mm verdünnt, damit die
Rastnasen greifen. Oben endet das Loch mit zwei 45°-Flanken 0,6 mm über
dem Kreis flach. So druckt es in der senkrechten Wand ohne Überhang, und
die Blende deckt die Kappe. Miss vor dem Druck den Körper des Schalters:
Ist er dicker als 20 mm, `schalter_d` anpassen.

**Nicht gemessen `[w]`:** die Einbaubuchse (Loch 8,2 für M8) und die
Wago-Klemmen nach Datenblatt: 221-415 30,2 × 18,8 × 8,6 mm, 221-420
(10 Leiter, zwei Reihen) 29,8 × 18,3 × 15,8 mm (Breite × Tiefe × Höhe, je
die größere Händlerangabe).

| Parameter | Wert | Wirkung |
|---|---|---|
| `geh_x0` | −205 mm | linke Außenkante des Kastens |
| `geh_abstand` | 11 mm | Kabelkanal zwischen Montageplatte und Kasten |
| `stapel_h` / `luft_luefter` | 28 `[v]` / 8 mm | Höhe Uno + Shield + Treiber, Luft bis zur Oberkante des Kastens — bestimmen die Kastenhöhe (gedruckt, nicht mehr ändern) |
| `deckel_aufbau` | 25 mm | Haube: so viel höher liegt die Platte mit dem Lüfter; bis etwa 65 mm möglich, 0 = flacher Deckel |
| `haube_dom_d` / `haube_kanal_d` / `haube_boden` | 11 / 6,5 / 3 mm | Säulen über den Domen, Kanal für Kopf und Inbus, Boden unter dem Kopf |
| `vert_b` | 94 mm | Breite des Verteilers (3 Wago nebeneinander) |
| `wandler_l` / `_b` / `_h` | 43 / 24 / 20 mm `[v]` | Wandler; `wandler_binder` 15 mm: Kabelbinder neben seiner Mitte |
| `buchse_d` | 8,2 mm | Loch der Einbaubuchse |
| `schalter_d` / `schalter_blende_d` / `schalter_wand` | 20,2 `[?]` / 22,5 `[v]` / 1,6 mm | runder Wippschalter: Einbauloch, Blende außen, Wand am Loch; `schalter_kappe` 0,6 mm: flache Kappe oben |
| `uno_schraube_d` | 2,8 mm | Kernloch in den Stehbolzen |

## Leistung: Reichen 72 W?

Ja, mit Reserve: Alles zusammen braucht **≈ 53 W**, das Netzteil gibt
dauernd 61 W ab.

| Verbraucher | Leistung |
|---|---|
| 4 × NEMA 17 (Stepperonline, 1,5 A) an TMC2209, je 1,05 A eingestellt | ≈ 23 W — je Motor 2 Phasen × (1,05 A)² × 2,3 Ω plus 0,6 W im Treiber; 2,3 Ω laut Datenblatt des 17HE15-1504S `[w]` |
| Lüfter 40 mm | ≈ 2 W |
| Laser LASER TREE 4 W: 12 V × 1,8 A (obere Angabe) = 21,6 W, über den Wandler (90 %) | ≈ 24 W |
| Pi, Uno, Treiberlogik und 3 Lichtschranken: zusammen 755 mA aus 5 V, über den 5-V-Wandler des Pi (85 %) | ≈ 4,4 W |
| **zusammen** | **≈ 53 W**, also ≈ 2,2 A auf der 24-V-Leitung |
| Netzteil, dauernd (85 % von 72 W) | 61 W — **≈ 8 W Reserve** |

Ein Chopper-Treiber zieht aus dem Netzteil nicht die Spulenströme, sondern
nur die Verluste in Wicklung und Treiber, dazu die mechanische Leistung —
bei einem Laser-Portal wenige Watt. Deshalb reichen für vier Motoren rund
23 W.

Wird das Steckernetzteil überlastet, schaltet es ab, und mit ihm gehen auch
Pi und Uno aus: Der Auftrag bricht mitten im Werkstück ab, und die SD-Karte
des Pi kann Schaden nehmen. Die Reserve ist dafür da. Ein stärkerer Laser (10 W Lichtleistung und mehr, meist
60 W Aufnahme `[w]`) bräuchte ein größeres 24-V-Netzteil — nicht über 28 V,
das vertragen die TMC2209 nicht.

## Endschalter

Alle drei als **LM393-Gabellichtschranke**, wie Z (Maße in
[hardware-notizen.md](hardware-notizen.md#endschalter)): 5 V direkt an die
Eingänge des Shields, ohne Pegelwandler. Der induktive LJ12A3 ginge an X
und Y auch, bräuchte aber 6–36 V und einen Optokoppler.

| Achse | wo | Fahne | Referenz |
|---|---|---|---|
| X | vor dem linken Ende des Portalrohrs (der 2020), Block an der X-Schiene; fährt mit dem Portal | Klammer unten an der Trägerplatte | nach links |
| Y | außen am **rechten** 2040, 35 mm hinter dem hinteren 2060, untere Nut | Klammer an der rechten Schlittenplatte | nach hinten |
| Z | am Toolhead (vorhanden) | Schaltfahne (vorhanden) | nach oben |

**Y rechts, weil links die Y-Kette läuft:** Die Fahne hinge außen neben dem
Schlitten, genau dort, wo links die Kette neben dem 2040 liegt, und der
obere Trum der Kette liegt über ihr. Rechts ist die Seite frei. Das Kabel
läuft mit dem des rechten Y-Motors an der Rückseite des 2060 entlang.

**X links, vor dem Rohr:** Am linken Wegende steht der X-Motor 3 mm neben
der Trägerplatte, und der X-Riemen läuft vom Ritzel zum Riemenhalter. Die
Lichtschranke sitzt deshalb nicht am Motor, sondern auf einem Block vor
dem linken Rohrende, der an das Ende der X-Schiene stößt. Die Fahne hängt
an einer Klammer unten an der Trägerplatte. Halter, Fahnen, Montage und
Einstellen: [endschalter.md](endschalter.md).

Die Näherungssensoren (LJ12A3) brauchst du dafür nicht, sie sind die
Reserve.

**Warum Y hinten am Schienenende referenziert:** Seit die 2060 435 mm
auseinander liegen (gemessen), kommt der Toolhead mit Z unten nicht mehr an
das hintere 2060 — am hinteren Schienenende steht er noch 26 mm davor. Nach
hinten begrenzen also die Y-Wagen, die dort bündig mit dem Schienenende
stehen. Der Schalter soll 3 mm davor schalten: Die Wagen dürfen nicht über
das Ende hinaus, sonst fallen Kugeln heraus. Der Weg der Softlimits reicht
dann vom Schaltpunkt bis 3 mm vor das vordere 2060 (Z unten): 333 mm
zwischen Schienenende und vorderem 2060 (227 hinter und 106 vor der Mitte),
davon gehen Schaltabstand und Rückzug ab.

Die GRBL-Einstellungen mit diesen Wegen (`$130`–`$132`, gerechnet aus den
Schaltpunkten) und den Test der Lichtschranken mit `?` und `$5` beschreibt
[verkabelung.md](verkabelung.md#grbl-einstellungen); angeschlossen werden
sie nach [verkabelung.md](verkabelung.md#4-5-v-und-lichtschranken-w6-w9w11).

## Kabel

**Fest verlegt** an den Nuten: an den 2040 in den
[Kabelhaltern](kabelhalter.md) unter der unteren Außennut (links fünf,
rechts vier), in der oberen Nut des Portalrohrs mit Nutabdeckungen oder
Clips:

* links aus dem Gehäuse, unter dem linken 2040 durch an die **untere Nut
  außen am linken 2040** — dort entlang zum linken Y-Motor (an den drei
  Trägern der Wanne Y in den Kabelhaltern unter ihrer Wand durch) und bis
  hinter die Wanne Y, dort hinein zum Festpunkt der Y-Kette;
* auf dem linken Y-Schlitten vom Kettenhalter Y hinter Stirnblock und
  Rückwand nach innen, in die **obere Nut des Portalrohrs** und darin zum
  Kabelflügel am Festpunkt der X-Kette; das fährt alles mit dem Portal;
* vorn aus dem Gehäuse in den Kabelkanal, darin nach rechts, dann an der
  **Rückseite des hinteren 2060** (mittlere Nut) zum rechten 2040 und in
  dessen unterer Nut außen nach vorn zum rechten Y-Motor bzw. nach hinten
  zum Y-Endschalter; das Kabel zum Not-Aus ebenso nach vorn. W18 (24 V zum
  Pi) verlässt die Nut unter dem [Pi-Halter](pi.md#halter) und läuft von
  unten in seine Haube zum 5-V-Wandler.
* hinten aus dem Gehäuse nur das USB-Kabel W17: aus dem USB-Fenster hinter
  dem Kasten nach rechts, an seiner rechten Wand nach vorn und von unten in
  die Haube des Pi-Halters. W19 (5 V vom Wandler in den Pi) bleibt am
  Pi-Halter: aus dem USB-A-Stecker nach unten und in einem Bogen von unten
  in PWR IN.
* Vorn belegt der [Y-Motorhalter](y-motorhalter.md) die letzten 30 mm der
  unteren Nuten beider Seitenflächen (Nutensteine), dahinter sitzen am
  vorderen 2060 die Winkel, die die 2040 halten. Das Motorkabel verlässt die
  Nut vor dem Winkel und läuft außen an Winkel und Schenkel zum Motor. Am
  hinteren 2060 sitzen ebenfalls Winkel (8 je Kreuzung), dort genauso.

**Bewegt** in zwei Energieketten:

| | Y-Kette | X-Kette |
|---|---|---|
| wo | außen am linken 2040, 3 mm neben der Schlittenplatte (die steht bis 12 mm über das 2040 hinaus) | direkt hinter der Trägerplatte, in einer Wanne über Portalrohr und X-Riemen |
| Hub | 333 mm, dazu 47 mm Reserve nach vorn | 391 mm |
| Festpunkt | hinten in der Wanne Y: Endstück 180 auf Wanne und Träger, 272 mm vom hinteren Ende des 2040 | Mitte des X-Wegs: Endstück 180 auf Wanne und Stütze |
| Schleife | nach vorn; die Wanne hängt an drei Trägern in der unteren Seitennut außen am 2040 | nach rechts — links stünde am Wegende der X-Motor darin |
| bewegtes Ende | Kettenhalter Y auf der Platte des linken Y-Schlittens, hinter dem Stirnblock | Kettenhalter hinten an der Trägerplatte, über dem Riemenhalter |
| Länge (R 20, mit Anfangs- und Endstück) | 16 Glieder, 328 mm (Arbeitsweg + Reserve) | 17 Glieder, 344 mm |
| darin | X- und Z-Motor, Laser, X- und Z-Endschalter: 17 Adern, 34 % gefüllt | Z-Motor, Laser, Z-Endschalter: 10 Adern, 21 % gefüllt |
| Stand | konstruiert (Portal Rev. 21), [energiekette.md](energiekette.md#y-kette) | konstruiert, [energiekette.md](energiekette.md) |

Beide Ketten sind **gedruckt** (Angabe vom 2026-10-01), nach dem Modell
„Energiekette“ von lingnau.florian: außen 18 × 14 mm, innen 10 × 8,8 mm,
Teilung 16, Biegeradius R 20: Um 180° gebogen ist die Schleife außen
50 mm hoch, 4 Gelenke knicken im Bogen (gemessen am 2026-10-02). Beide
Ketten sind gleich groß. Die
gekauften Ketten mit 10 × 20 mm innen und 15 × 27 mm außen braucht es
nicht mehr. Gezeichnet sind beide so, wie `Portal.py` sie baut, in der
Seitenansicht die Y-Kette mit dem Portal am hinteren Schienenende.

Die Längen bis zum Gerät (Weg wie gezeichnet, 15 % Reserve, aufgerundet)
stehen mit Litze, Weg und Kette jeder Leitung in der Kabelliste von
[verkabelung.md](verkabelung.md#leitungen); `tools/elektronik_zeichnen.py`
gibt sie auch beim Zeichnen aus.

In den Ketten nur **Einzellitzen aus Silikon**, keine Mantelleitungen,
kein Massivdraht und keine starren Flachbandkabel: Für Mantelleitungen ist
R 20 zu eng ([energiekette.md](energiekette.md#litzen-in-der-kette)). Die üblichen 1-m-Motorkabel
reichen also nur links und für X. Der Laser bekommt ein eigenes 3-adriges
Kabel mit XH-Stecker ([Einkaufsliste](#einkaufsliste-vorschlag)).

### Litzen

Kupfer, feindrähtig. Der Querschnitt folgt aus Strom und Länge und aus dem,
was Stecker und Klemmen nehmen `[w]`: XH-Crimpkontakt 0,08–0,34 mm²
(AWG 28–22), PH 0,05–0,22 mm² (AWG 30–24), Dupont AWG 28–22, Wago 221
feindrähtig 0,14–4 mm². Gerechnet in `tools/elektronik_zeichnen.py`, geprüft
in `tools/elektronik_check.py` (Abschnitt 14), jeweils am längsten Weg:

| Leitung | Strom | Litze | warum |
|---|---|---|---|
| 24 V: Buchse → Schalter → Not-Aus → Wago +24 V, Buchse − → Wago GND, Wago → Shield und Wandler | bis 3 A (Netzteil) | **0,75 mm² (AWG 18)**, rot und schwarz | belastbar 6 A (VDE 0298-4, flexible Leitung); 0,5 mm² hätte genau die 3 A. Not-Aus 1,5 m hin und zurück: 0,21 V bei 3 A |
| 24 V zum Pi (W18): Buchse → 5-V-Wandler | 0,19 A, bei einem Kurzschluss im Wandler bis 3 A | **2 × 0,75 mm²**, rot und schwarz | wie die 24-V-Leitung, weil sie vor Schalter und Not-Aus hängt: Das Netzteil begrenzt erst bei 3 A. 0,5 m: 0,004 V |
| 5 V und USB (W19, W17) | W19 0,76 A (alles an 5 V), W17 0,15 A (Uno, Treiberlogik, Lichtschranken) | fertige USB-Kabel; W19 mit Stromadern AWG 24 | W19 0,25 m: 0,03 V mit AWG 24, 0,08 V mit dünnen AWG 28, am Pi bleiben 4,92 V; unter ≈ 4,63 V meldet er Unterspannung `[w]`. W17 1 m: 0,07 V mit AWG 28 |
| Laser: +12 V, GND, PWM | 1,8 A | **3 × 0,34 mm² (AWG 22)** | dicker passt nicht in den XH-Kontakt am Laser; 2 m: 0,37 V = 3 % von 12 V |
| Motoren | 1,05 A je Spule | **4 × AWG 24 (0,2 mm²)** | dicker passt nicht in den PH-Kontakt am Motor; Z-Motor, 2 m: 0,35 Ω = 15 % der Wicklung. Fertige Motorkabel mit AWG 26 gehen auch (24 %) |
| Endschalter: 5 V, GND, Signal | ≈ 20 mA | **3 × 0,25 mm² (AWG 24)** | 0,14 mm² ist das Minimum der Wago (AWG 26 hat nur 0,13); in den Dupont-Kontakt passen bis 0,34 |
| Lüfter | < 0,1 A | seine eigene Anschlusslitze | |

* In Schraubklemmen (Shield, Wandler, Not-Aus) mit **Aderendhülse**, in die
  Wago ohne.
* In den Ketten nur Einzellitzen aus Silikon, die Motorkabel nur als lose
  Adern ohne Schlauch. Die gedruckten Ketten biegen mit R 20, dafür sind
  Mantelleitungen zu steif.
* Die Y-Kette trägt fünf Leitungen (X- und Z-Motor, Laser, X- und
  Z-Endschalter) mit 17 Adern, die X-Kette drei mit 10 Adern. Innen sind
  10 × 8,8 mm frei. Die Adern füllen das zu 34 und 21 %, höchstens 60 %
  sind gut `[w]` (Prüfung in `tools/elektronik_check.py`).

## Anschlussplan

Anschlussplan

Kein 230 V in der Maschine: Das Steckernetzteil liefert 24 V, am Rahmen muss
nichts geerdet und keine Netzklemme abgedeckt werden.

Die Verdrahtung Leitung für Leitung (W1–W19), die Belegung von Wago-Klemmen
und Shield, die Reihenfolge beim Anschließen und die Inbetriebnahme mit
Tests stehen in [verkabelung.md](verkabelung.md). Plan und Tabellen
entstehen aus derselben Kabelliste (`tools/verkabelung.py`).

Die 24 V teilen sich an der Einbaubuchse in zwei Zweige:

```
Netzteil ── Buchse ─┬─ W1 ── Schalter ── W2 ── Not-Aus ── W2 ── Wago +24 V: Shield, Wandler 12 V, Lüfter
                    └─ W18 ── 5-V-Wandler ── W19 ── Pi ── W17 (USB) ── Uno ── Wago +5 V: Lichtschranken
```

* **Zweig mit Schalter und Not-Aus:** Shield (Motoren), Abwärtswandler
  12 V (Laser) und Lüfter. Fehlen hier die 24 V, meldet der 24-V-Wächter
  (W16) das an GRBL, und GRBL bricht ab.
* **Zweig zum Pi:** W18 ist an der Buchse angelötet, **vor** Schalter und
  Not-Aus. Der 5-V-Wandler auf dem [Pi-Halter](pi.md#halter) gibt über W19
  5 V in **PWR IN** des Pi. Über W17 an der Buchse **USB** bekommt der Uno
  Daten und 5 V. Über seinen 5-V-Stift versorgt der Uno die Wago +5 V und
  damit die Lichtschranken. Pi und Uno laufen also, sobald das Netzteil
  steckt. Einschalten heißt: Netzteil einstecken, dann den Schalter
  ([pi.md, Strom](pi.md#strom)).
* **Masse:** Buchse − an die Wago GND, dazu IN− des 5-V-Wandlers (W18) und
  über USB der Pi. Pi, Uno und Shield haben so dieselbe Masse.

Zu den Teilen:

* **Abwärtswandler:** vorhanden, **12 V / 5 A**, 43 × 24 × 20 mm `[v]`.
  Der Laser zieht höchstens 1,8 A, der Wandler ist damit zu 36 % belastet —
  reichlich Luft.
* **Treiber:** GERUI TMC2209 V2.0 mit Kühlkörper (5 Stück: 4 + Ersatz),
  standalone, 1/16 über MS1 + MS2. Strom am Vref-Poti, Ziel **1,05 A eff.**
  = 70 % des Nennstroms 1,5 A. Vref hängt vom Messwiderstand ab: **1,37 V**
  bei R100, **1,48 V** bei R110, **1,94 V** bei R150. Ein Aufdruck R110 ist
  auf den Modulen nicht zu finden — deshalb **mit 1,37 V anfangen**: Das
  gibt bei jedem der drei höchstens 1,05 A. Rechnung und Vorgehen in
  [hardware-notizen.md](hardware-notizen.md#treiber-und-versorgung).
* **5-V-Wandler:** 24 → 5 V, 63 × 30 mm `[v]`, mindestens 3 A, Eingang
  mit Schraubklemmen, Ausgang USB-A. Er liefert höchstens 0,76 A und ist
  damit zu einem Viertel belastet.
* **Sicherung:** braucht es nicht, auch nicht im Zweig zum Pi. Das Netzteil
  begrenzt den Strom selbst.

## Einkaufsliste (Vorschlag)

| Menge | Teil | wofür |
|---|---|---|
| 1 | Abwärtswandler 24 → 12 V / 5 A, 43 × 24 × 20 mm | vorhanden |
| 1 | Einbaubuchse 5,5 × 2,1 mm mit M8-Gewinde (Gehäuse: Loch 8,2) | 24-V-Eingang |
| 1 | Wippschalter rund (Blende Ø22,5, Einbauloch Ø20), ≥ 3 A | EIN/AUS |
| 1 | Lüfter 40 × 40 × 10 mm, 24 V | über den Treibern |
| 2 | Energiekette, gedruckt: Anfangsstück und Endstück 180, 17 Glieder für X, 16 für Y (gleiche Größe) | X und Y; Wannen, Stützen, Träger und Halter: [energiekette.md](energiekette.md#verschraubung) |
| 1 + 2 | Wago 221-415 (+24 V), 221-420 (GND, +5 V); 221-413 Reserve | vorhanden |
| — | Not-Aus, Kabel, Litzen, Stecker, Aderendhülsen, Pull-down | [verkabelung.md](verkabelung.md#material-und-werkzeug) |
| 4 + 4 | M5×12 + Hammermutter M5 (Nut 6) | Gehäuse → Rückseite des 2060 |
| 4 + 4 | M3×8 + Messing-Einsatz M3 Ø5 | Deckel |
| 4 | M3×8 | Uno → Stehbolzen |
| 4 + 4 | M3×16 + M3-Mutter | Lüfter → Deckel |
| 2 | Kabelbinder 2,5 × 200 (2,5 × 100 ist zu kurz), doppelseitiges Klebeband | Wandler, Wago |
| 1 | Pi Zero 2 W, 5-V-Wandler, USB-Kabel, Pi-Halter mit Haube, Schrauben und Einsätze | ohne PC: [pi.md](pi.md#teile) |

## Was noch fehlt

1. **Endschalter:** Halter und Fahnen für X und Y sind gezeichnet und
   geprüft ([endschalter.md](endschalter.md)). Offen sind dort vier
   Kleinigkeiten am Aufbau: Boden des Gabelschlitzes, Lötstifte, ein
   Schmiernippel am X-Wagen und der Lagerbock der hinteren Umlenkung
   ([Noch offen](endschalter.md#noch-offen)).
2. **Energieketten** (gedruckt): Beide sind konstruiert, mit Wanne,
   Festpunkt und Kettenhalter, dazu der Kabelweg in der oberen Nut des
   Rohrs ([energiekette.md](energiekette.md)). Die Schleife ist gemessen
   (R 20), der linke Schlitten ist gedruckt und wird mit der Lehre
   nachgebohrt. Offen ist dort nur noch, ob die gedruckte Kette breiter
   als 18 mm ist.
3. **Treiber:** Messwiderstand unbekannt — mit Vref 1,37 V anfangen (siehe
   [Anschlussplan](#anschlussplan)). Wer den Aufdruck der zwei kleinen
   Widerstände neben dem Chip findet (je nach Modul oben oder unten),
   stellt nach der Tabelle ein.
4. **Winkel vor dem vorderen 2060:** Sitzt ein Winkel mit einem Schenkel an
   der Seitenfläche der 2040 **vor** dem 2060, also in den 35 mm bis zur
   Stirnseite? Dort belegt der [Y-Motorhalter](y-motorhalter.md) die untere
   Nut.
5. **Verkabelung:** drei Dinge, die sich erst beim Anschließen zeigen
   ([verkabelung.md](verkabelung.md#noch-offen)).
6. **Pi:** Lochbild und Buchsen des Pi sind nach dem Maßblatt gezeichnet,
   vor dem Druck den Pi auf die Zeichnung legen
   ([pi.md](pi.md#noch-offen)).

Geklärt (2026-09-25/26): Netzteil ist das Steckernetzteil 24 V / 3 A mit
Hohlstecker 5,5 × 2,1; der Laser ein LASER TREE 4 W mit 12 V / 1,6 A;
Lüfter 24 V; Gabellichtschranken für X und Y sind da, Näherungssensoren
als Reserve; Wago-Klemmen sind da. 2026-09-27: das CNC Shield V3 ist da;
die 2040 sitzen mit Winkeln an den 2060 (8 je Kreuzung, zwei davon in der
oberen Nut); Stapelhöhe 28 mm, Lochbild des Uno stimmt; Motoren
Stepperonline NEMA 17 (1,5 A); Treiber GERUI TMC2209 V2.0; die 2040 stehen
hinten 110 mm über; Wandler 43 × 24 × 20 mm; Wago: 1 × 221-413,
1 × 221-415, 2 × 221-420; Ketten 10 × 20 mm innen. Später am 2026-09-27:
Ketten 15 × 27 mm außen, je 1 m; Wandler 12 V / 5 A; 5 Treiber, ohne
Aufdruck R110; Motoren 17HE15-1504S (Etikett); hinteres Y-Ritzel mittig
zur 2040; die Winkel greifen in die obere Nut des 2060 und die untere der
2040; Laserstecker von links PWM · GND · +12 V. 2026-09-29: Winkel an den
Kreuzungen 20 mm; die Nuten für die Endschalterhalter sind frei; eine
Klammer an der Trägerplatte ist in Ordnung. 2026-09-30: der Not-Aus ist da,
ein Pilztaster mit Wechsler C/NO/NC und Lötfahnen, 3 A / 250 V, Gewinde
16 mm rund; er sitzt vorn. 2026-10-01: Die Energieketten werden gedruckt,
nach dem Modell „Energiekette“, auch für Y; die X-Kette liegt direkt
hinter der Trägerplatte; ein Glied dreht sich am gedruckten Teil höchstens
um 30°, gedruckt ist bisher eine Kette. Die Litzen zur X-Kette laufen in
der oberen Nut des Rohrs, am Festpunkt hält sie ein Halter mit
Kabelbindern; die Y-Kette reicht für den Arbeitsweg plus 26 mm; die Nut an
der Unterseite des linken 2040 ist belegt; die Motorkabel haben lose Adern
in einem Schlauch. 2026-10-02: Um 180° gebogen ist die Schleife außen
50 mm hoch, 4 Gelenke knicken im Bogen (die 30° waren zu klein); der linke
Y-Schlitten ist schon gedruckt; in der unteren Seitennut sitzen zwischen
den 2060 nur die Winkel.

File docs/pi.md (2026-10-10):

# Pi — die Maschine ohne PC bedienen

Ein **Raspberry Pi Zero 2 W** steckt statt eines Rechners am USB des Uno.
Auf ihm läuft [CNCjs](https://cnc.js.org/), eine Weboberfläche für GRBL.
Aufträge entwirfst du weiter in LightBurn auf dem Mac und speicherst sie als
G-Code-Datei. Die Datei liegt dann auf dem Pi, und gestartet wird im
Browser: am iPad, am iPhone oder am Mac. Der Pi schickt die Datei selbst
über USB an den Uno. Bricht das WLAN ab, läuft der Auftrag deshalb weiter.

Der Pi sitzt mit seinem 5-V-Wandler auf einem gedruckten
[Halter](#halter) rechts neben dem Elektronik-Kasten, unter einer
[Haube](#haube) wie die Elektronik: Von außen sieht man keine Platine. Er
hängt **vor
Schalter und Not-Aus** am Netzteil: Pi und Uno laufen, solange das Netzteil
steckt. Not-Aus und Schalter trennen nur Motoren, Laser und Lüfter, und der
[24-V-Wächter](verkabelung.md#7-24-v-wächter-w16) meldet das wie bisher an
GRBL.

Pi-Halter von hinten und im Schnitt

Die Dateien für den Pi stehen in [`pi/`](../pi). Das Einrichtungsskript,
der Dienst und die Konfiguration mit Makros und Befehlen sind mit
**CNCjs 1.11.5** geprüft. Der Halter kommt aus `fusion/PiHalter/PiHalter.py`
und ist mit `python3 tools/pihalter_check.py` geprüft. Die Leitungen W17–W19
stehen mit allen anderen in [verkabelung.md](verkabelung.md#8-pi-w17w19).

**Nie unbeaufsichtigt lasern.** Der Stopp-Knopf im Browser hängt am WLAN
und ist keine Sicherheitsfunktion. Der Not-Aus bleibt in Reichweite.

## Teile

| Menge | Teil | wofür |
|---|---|---|
| 1 | Raspberry Pi Zero 2 W (ohne Stiftleiste genügt) | CNCjs |
| 1 | microSD-Karte 16–32 GB | Raspberry Pi OS Lite |
| 1 | Abwärtswandler 24 → 5 V, ≥ 3 A, Eingang bis mindestens 28 V; 63 × 30 mm, höchstens 20 mm hoch, Schraubklemmen und USB-A-Buchse an den schmalen Seiten `[v]` | 5 V für Pi und Uno |
| 1 | USB-Kabel A → Micro-B, 0,25 m, Stromadern mindestens AWG 24 | W19 |
| 1 | OTG-Kabel Micro-B → USB-B, 1 m | W17 |
| 0,5 m | Leitung 2 × 0,75 mm², rot/schwarz (wie W2) | W18 |
| 1 + 1 | Pi-Halter und Haube, PETG: [`stl/PiHalter_r3.stl`](../stl/PiHalter_r3.stl), [`stl/PiHalter_Haube_r3.stl`](../stl/PiHalter_Haube_r3.stl) | Halter |
| 2 + 2 | M5×12 Zylinderkopf + Hammermutter M5 Nut 6 | Halter → obere Nut des 2060 |
| 4 | M2.5×6 Zylinderkopf | Pi → Stehbolzen |
| 3 + 3 | M3×8 Zylinderkopf + Messing-Einsatz M3 Ø5 (wie am Deckel des Kastens) | Haube → Dome |
| 2 | Kabelbinder 2,5 × 200 (2,5 × 100 ist zu kurz) | Wandler |

Ein OTG-Kabel verbindet im Micro-B-Stecker den ID-Stift mit Masse; dann
arbeitet der Pi an dieser Buchse als Host. Solche Kabel gibt es für Handys
an Druckern.

## Halter

Eine Platte, 190 × 63,4 × 5 mm, liegt wie die Montageplatte des Kastens
an der Rückseite des hinteren 2060, 5,7 mm rechts neben ihr. Zwei M5×12
halten sie in Hammermuttern der **oberen Nut**. Unten reicht sie 6 mm unter
die Mitte dieser Nut. Die Kabel in der mittleren Nut (W2, W10, W14, W18)
laufen 8 mm darunter frei durch.

Oben steht die Platte 47 mm über das 2060 hinaus. Dort sitzen:

* **rechts der Pi** auf vier Stehbolzen (5 mm hoch, Lochbild 58 × 23 mm
  `[w]`), Bauteile nach hinten, Buchsen nach unten, die SD-Karte rechts
  (von hinten gesehen links). Der Pi liegt ganz über der Oberkante des 2060,
  5 mm darüber. Vor seiner Antenne ist kein Aluminium.
* **links der 5-V-Wandler**, Eingang zur Kastenseite, USB-A-Buchse zum Pi.
  Er hat keine Befestigungslöcher: Zwei Kabelbinder laufen senkrecht über
  seine Rückseite, durch Schlitze über und unter ihm, und ziehen ihn an die
  Platte. Beide Enden mit Eingang und Buchse bleiben frei. Der
  Wandler ist 63 × 30 mm und höchstens 20 mm hoch `[v]`. Links von ihm
  bleiben in der Haube 12 mm: Dort kommt W18 von unten zu den
  Schraubklemmen, mit Aderendhülsen und Bogen nach unten.
* dazwischen **40 mm** für den USB-A-Stecker, bevor das Kabel nach unten
  zum Pi abbiegt.
* **drei Dome** mit Messing-Einsätzen M3 für die Haube: einer oben zwischen
  Wandler und Pi, zwei unten.

### Haube

Die Haube deckt Pi und Wandler nach hinten, oben und zu den Seiten ab, wie
die Haube auf dem Elektronik-Kasten. Ihre Wände sind 2 mm dick und stehen
auf der Platte, im selben Umriss. 3 × M3×8 halten sie in den Einsätzen der
Dome. Die Dome enden 0,3 mm vor der Rückwand, so ziehen die Schrauben die
Haube fest auf die Platte.

* **Unten offen:** Dort kommen die Kabel heraus, und dort strömt kühle Luft
  nach.
* **Lüftung:** 6 Schlitze 20 × 3 mm oben in der Rückwand. Die warme Luft
  steigt dorthin. Die Schlitze liegen über Pi und Wandler, durch sie sieht
  man keine Platine.
* **Wärme:** Hinter dem Pi bleiben 15 mm frei. Da passt ein kleiner
  Kühlkörper auf den Prozessor, falls der Pi zu warm wird
  ([Fehlersuche](#fehlersuche)).
* **WLAN:** PETG dämpft das WLAN kaum. Kein Filament mit Kohlefaser oder
  Metall nehmen.
* **SD-Karte:** Zum Wechseln die Haube abnehmen.

| | |
|---|---|
| Lage | X −18 bis +172 (Maschinenkoordinaten wie `Portal.py`), Z −85 bis −21,6; die Haube reicht 28 mm nach hinten |
| Freiraum | 6,7 mm zum X-Wagen mit dem Portal am hinteren Schienenende (die engste Stelle über den ganzen Weg; bis Rev. 2 waren es 8,6 mm, die Platte ist seit Rev. 3 oben 3 mm höher), 5,7 mm zur Montageplatte des Kastens, 8 mm über den Kabeln |
| Schrauben | 2 × M5×12 wie die Montageplatte: 5,2 mm im Stein, 0,5 mm vor dem Nutgrund. Inbus von hinten, bevor die Haube draufkommt |
| Pi | 4 × M2.5×6 selbstschneidend in Kernlöcher Ø 2,2; die Schraube greift 4,4 bis 5 mm |
| Haube | 3 × M3×8 in Messing-Einsätzen M3 Ø5 (Bohrung 4,6, 7 mm tief), 5,7 mm im Gewinde. Inbus von hinten |
| Druck | PETG, keine Stützen. Halter: die Seite am 2060 aufs Bett, Stehbolzen und Dome nach oben, 31 mm hoch, ≈ 84 g voll. Haube: Rückwand aufs Bett, 28 mm hoch, ≈ 50 g |

`python3 tools/pihalter_check.py` prüft das alles gegen Portal, Toolhead,
Kasten, Rahmen und Kabel, dazu die Haube: innen frei, Dome, Schrauben,
Lüftung. `python3 tools/pihalter_zeichnen.py` zeichnet
[`pihalter.svg`](pihalter.svg), `python3 tools/stl_export.py PiHalter`
schreibt beide STL.

**Montage:**

1. Den Pi vor dem Druck auf die Zeichnung legen: Lochbild und Buchsen sind
   nach dem Maßblatt der Zero-Reihe gezeichnet `[w]`.
2. Die drei Messing-Einsätze M3 mit dem Lötkolben bündig in die Dome
   einschmelzen.
3. Pi mit 4 × M2.5×6 auf die Stehbolzen, Buchsen nach unten.
4. Wandler links auf die Platte legen, Eingang nach links. Je einen
   Kabelbinder 2,5 × 200 von hinten durch den oberen Schlitz, auf der Seite
   zum 2060 hinunter, durch den unteren Schlitz zurück und über den Wandler.
   Die Schlaufe wird bis 118 mm lang, ein Binder 2,5 × 100 schließt nur
   etwa 75 mm. Die Köpfe hinten auf den Wandler, am besten neben das
   höchste Bauteil. Von Hand festziehen, bis nichts mehr wackelt, nicht mit
   der Zange nachziehen. Die Enden bündig abschneiden, sonst stoßen sie an
   die Haube. Unter den Wandler muss nichts: Er liegt mit den Lötstellen auf
   dem PETG, das isoliert.
5. 2 Hammermuttern in die obere Nut der Rückseite des hinteren 2060, rechts
   neben der Montageplatte des Kastens. Halter ansetzen, 2 × M5×12.
6. Verdrahten wie in [verkabelung.md, Schritt 8](verkabelung.md#8-pi-w17w19).
7. Haube aufsetzen, 3 × M3×8.

## Strom

```
Netzteil ── Buchse ─┬─ Schalter ── Not-Aus ── Wago +24 V: Shield, Wandler 12 V, Lüfter
                    └─ W18 ── 5-V-Wandler ── W19 ── Pi ── W17 (USB) ── Uno ── 5 V der Lichtschranken
```

| Zustand | Pi und Uno | Motoren, Laser, Lüfter |
|---|---|---|
| Netzteil gesteckt, Schalter aus | an, GRBL meldet `Pn:R` | aus |
| Schalter an | an | an |
| Not-Aus gedrückt | an, GRBL bricht ab: ALARM, `Pn:R` | aus |
| Netzteil gezogen | aus, der Pull-down W8 hält den Laser aus | aus |

* **Einschalten:** Netzteil einstecken. Der Uno bekommt seine 5 V sofort
  über W17 vom Pi, nicht erst, wenn der Pi gestartet ist. GRBL läuft nach
  etwa einer Sekunde und steht bis zur Referenzfahrt in ALARM: Es nimmt
  keinen G-Code an, auch kein `M3`. Den Schalter darfst du deshalb gleich
  anschalten, auch während der Pi noch startet. Der Laser bleibt aus, und
  kein Motor fährt. Nach etwa einer Minute ist CNCjs erreichbar: erst
  verbinden, dann **Homing** (beim Verbinden startet der Uno neu).
* **Ausschalten:** Schalter aus, in CNCjs **Pi herunterfahren**, erst dann
  das Netzteil ziehen. Ein harter Stromausfall kann die SD-Karte
  beschädigen. Steckt das Netzteil weiter, bleibt der Pi erreichbar
  (≈ 1 W im Leerlauf).
* **Leistung:** Pi, Uno, Treiberlogik und Lichtschranken ziehen zusammen
  höchstens 755 mA aus 5 V. Mit dem Wandler (85 %) sind das ≈ 4,4 W aus dem
  Netzteil. Zusammen mit allem anderen sind es ≈ 53 W, dauernd gehen 61 W
  ([Leistung](elektronik.md#leistung-reichen-72-w)).

## Einrichten

**1. Karte beschreiben** (am Mac, Raspberry Pi Imager):

* Gerät „Raspberry Pi Zero 2 W“, System „Raspberry Pi OS Lite (64-bit)“.
* In den Einstellungen: Hostname **laser**, Benutzer und Passwort (hier im
  Beispiel `laser`), WLAN mit Land DE (der Zero kann nur 2,4 GHz), SSH an.

**2. Dateien auf den Pi**, im Ordner des Repos am Mac:

```sh
scp -r pi laser@laser.local:
ssh laser@laser.local
```

**3. Auf dem Pi:**

```sh
sh pi/einrichten.sh
sudo reboot
```

Das Skript ([`pi/einrichten.sh`](../pi/einrichten.sh)) installiert Node.js
und CNCjs 1.11.5 und legt den Ordner `~/gcode` an. Es schreibt
[`pi/cncrc.json`](../pi/cncrc.json) als `~/.cncrc` und richtet CNCjs als
Dienst ein ([`pi/cncjs.service`](../pi/cncjs.service)). CNCjs startet dann
mit dem Pi. Dazu erlaubt es die Befehle zum Herunterfahren und Neustarten
([`pi/sudoers-cncjs`](../pi/sudoers-cncjs)) und schaltet das
WLAN-Energiesparen ab
([`pi/wlan-energiesparen-aus.conf`](../pi/wlan-energiesparen-aus.conf)).
Ohne das hält der Pi Pakete zurück, und Joggen und Anzeige im Browser
haken. Eine vorhandene `~/.cncrc` bleibt, wie sie ist. Auf dem Zero dauert
der Lauf einige Minuten.

## CNCjs

Im Browser: **`http://laser.local:8000`**. Am iPad oder iPhone in Safari
„Zum Home-Bildschirm“, dann öffnet es sich wie eine App. Ein altes iPad an
der Maschine ist ein gutes Bedienfeld.

* **Verbinden:** Port `/dev/ttyACM0` (Uno mit Nachbau-Chip CH340:
  `/dev/ttyUSB0`), 115200 Baud, Controller Grbl. Beim Verbinden startet der
  Uno neu, wie am Mac auch.
* **Nach dem Verbinden „Homing“** (`$H`), nicht „Unlock“ (`$X`): Die
  Softlimits stimmen nur nach der Referenzfahrt
  ([endschalter.md](endschalter.md#softlimits-statt-zweitem-y-schalter)).
* Nur aus dem Heimnetz erreichbar: CNCjs lässt ohne `allowRemoteAccess`
  nur private Adressen zu. Wer im WLAN nicht allein ist, legt unter
  Settings → User Accounts einen Zugang an.

Vorbereitet in [`pi/cncrc.json`](../pi/cncrc.json):

| Makro / Befehl | was | |
|---|---|---|
| **Rahmen** | fährt mit G0 die Außenkante der geladenen Datei ab, der Laser bleibt aus | `G0 X[xmin] Y[ymin]` … |
| **Laserpunkt 1 %** | Laser als Punkt an, z. B. für den [Nullpunkt](spannmittel.md#nullpunkt-einrichten-einmal); **Schutzbrille** | `G1 F600`, `M3 S10` |
| **Laser aus** | | `M5` |
| **Pi herunterfahren** (Befehl) | vor dem Ziehen des Netzteils | `sudo shutdown -h now` |
| **Pi neu starten** (Befehl) | | `sudo reboot` |

Die Außenkante für **Rahmen** liefert die 3D-Ansicht von CNCjs, wenn sie
die Datei geladen hat. Ist die 3D-Ansicht abgeschaltet, kennt CNCjs die
Kante nicht.

## LightBurn auf dem Mac

* **Nullpunkt** einmal einrichten wie in
  [spannmittel.md](spannmittel.md#nullpunkt-einrichten-einmal): an der
  Innenecke des Anschlags hinten links mit `G10 L20 P1 X0 Y0`. GRBL behält
  ihn. In LightBurn den Ursprung hinten links.
* Aufträge mit **„Start From: Absolute Coords“** anlegen und mit **„Save
  GCode“** speichern. So bezieht sich die Datei auf diesen Nullpunkt und
  läuft im Pi genauso wie direkt aus LightBurn. „Current Position“ und
  „User Origin“ gehören zu LightBurn am Kabel.
* „Constant Power Mode“ aus lassen (Standard, M4): Dann regelt GRBL die
  Leistung mit der Geschwindigkeit und hält den Laser im Stillstand aus.
* **Übertragen:**
  * im Browser mit „Upload G-code“. Die Datei bleibt geladen, bis CNCjs neu
    startet;
  * oder dauerhaft in den Ordner auf dem Pi:
    `scp auftrag.gc laser@laser.local:gcode/`. In CNCjs erscheint sie unter
    „Watch Directory“.

## Ablauf an der Maschine

1. Netzteil einstecken und warten, bis CNCjs erreichbar ist.
2. CNCjs öffnen, verbinden, Schalter an, **Homing**.
3. Werkstück an den Anschlag ([spannmittel.md](spannmittel.md)), Datei laden.
4. Makro **Rahmen**, die Hand am Not-Aus. Dann **Start**.
5. Bleib dabei, bis der Auftrag fertig ist.
6. Schalter aus. Soll die Maschine ganz aus: **Pi herunterfahren**, dann das
   Netzteil ziehen.

## Fehlersuche

| Was passiert | Ursache | Abhilfe |
|---|---|---|
| `laser.local` nicht erreichbar | Pi startet noch, WLAN-Daten falsch, 5-GHz-Netz | eine Minute warten; im Router nach dem Pi sehen; der Zero braucht 2,4 GHz |
| Seite lädt nicht, Pi antwortet auf `ping` | Dienst läuft nicht | auf dem Pi `systemctl status cncjs` und `journalctl -u cncjs` |
| Kein Port in CNCjs | W17 in PWR IN statt USB, Kabel ohne OTG | Micro-B in die mittlere Buchse **USB**; OTG-Kabel; `ls /dev/ttyACM* /dev/ttyUSB*` |
| Pi startet neu, Blitz-Symbol, Unterspannung | W19 dünn oder lang, Wandler zu schwach | kurzes Kabel mit dicken Adern; Wandler ≥ 3 A; am USB-Ausgang 5,0–5,2 V |
| Joggen und Anzeige haken | WLAN-Energiesparen an | `iw dev wlan0 get power_save` muss „off“ zeigen; sonst Schritt 3 wiederholen |
| ALARM:2 oder `error:15` beim Rahmen | Datei nicht auf den Nullpunkt bezogen | Nullpunkt prüfen, in LightBurn „Absolute Coords“ und Ursprung hinten links |
| Rahmen fährt nach 0, 0 | 3D-Ansicht aus oder keine Datei geladen | Datei laden, 3D-Ansicht an |
| Befehl „Pi herunterfahren“ tut nichts | sudo fragt nach dem Passwort | `pi/einrichten.sh` noch einmal laufen lassen (legt `/etc/sudoers.d/cncjs` an) |
| CNCjs wird träge, `vcgencmd measure_temp` zeigt um 80 °C | Pi zu warm unter der Haube, ab 80 °C drosselt er | Lüftungsschlitze frei halten, einen kleinen Kühlkörper auf den Prozessor kleben |

## Noch offen

**Pi** `[w]`: Lochbild und Lage der Buchsen nach dem Maßblatt der
Zero-Reihe, Platinendicke und Bauteilhöhe `[?]`. Vor dem Druck den Pi auf
die Zeichnung legen. Der 5-V-Wandler ist geklärt (2026-10-10, seit Rev. 2
im Halter).

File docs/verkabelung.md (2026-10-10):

# Verkabelung — Strom, Motoren, Lichtschranken, Laser

Die ganze Verdrahtung, vom Steckernetzteil bis zum Laser, Schritt für
Schritt. Jede Leitung hat eine Nummer (W1 … W19). Sie steht an beiden Enden
auf dem Kabel, im [Anschlussplan](elektronik-anschluss.svg) und in den
Tabellen hier.

Die Kabelliste steht einmal in `tools/verkabelung.py`. Daraus entstehen die
Tabellen dieser Anleitung (`python3 tools/verkabelung.py`, schreibt nur
zwischen den Markierungen), der Anschlussplan
(`python3 tools/anschluss_zeichnen.py`) und das Bild zu
[Schritt für Schritt](#schritt-für-schritt)
(`python3 tools/verkabelung_zeichnen.py`). `python3 tools/elektronik_check.py`
prüft in Abschnitt 15 die Netze (kein Kurzschluss, der Not-Aus trennt die
24 V von Shield, Wandler und Lüfter, der Pi hängt davor), Signale und Pins,
Kontakte, Klemmen und Längen und ob die Tabellen hier aktuell sind. Wo
Gehäuse, Kabelwege und Ketten liegen, steht
in [elektronik.md](elektronik.md). Pins, Treiber und Jumper im Einzelnen
stehen in [hardware-notizen.md](hardware-notizen.md#elektronik).

Anschlussplan

## Vorab: sechs Regeln

1. **Nichts unter Spannung an- oder abstecken**, vor allem keine Motoren.
   Ein Motorstecker, der unter Strom abgeht, kostet den Treiber.
2. **Die 24 V messen, bevor das Shield dran ist.** Verpolt sind die
   Treiber hin.
3. **Den Wandler ohne Laser auf 12,0 V stellen.**
4. **Einschalten: erst das Netzteil einstecken, dann den Schalter.** Der
   [Pi](pi.md) hängt vor dem Schalter und gibt dem Uno über USB sofort 5 V,
   auch während er selbst noch startet. GRBL läuft nach etwa einer Sekunde
   und hält den Laser aus, wenn er Strom bekommt; auf den Pi musst du nicht
   warten. Ausschalten umgekehrt, den Pi vor dem Ausstecken herunterfahren.
   Hängt statt des Pi der Mac am Uno: erst USB, dann 24 V.
5. **Beim ersten Lasertest eine Schutzbrille für 450 nm tragen**, auch bei
   wenig Leistung.
6. **Jede Leitung an beiden Enden mit ihrer W-Nummer beschriften.**

## Übersicht

Drei Spannungen, eine gemeinsame Masse:

| Spannung | kommt von | versorgt | geschaltet |
|---|---|---|---|
| **+24 V** | Steckernetzteil 24 V / 3 A über Einbaubuchse, Schalter und Not-Aus | Shield (vier Treiber), Wandler, Lüfter | Schalter und Not-Aus |
| **+24 V vor dem Schalter** | Einbaubuchse, W18 | nur den 5-V-Wandler des Pi | nicht: an, solange das Netzteil steckt |
| **+12 V** | Wandler 24 → 12 V | nur den Laser | mit den 24 V |
| **+5 V** | 5-V-Wandler → Pi → USB (W17) → Uno, Stift 5V am Shield | Pi, Uno, die drei Lichtschranken | nicht: wie der 5-V-Wandler |
| **GND** | alles verbunden, Stern an der Wago GND | | |

Signale: Die Lichtschranken X, Y und Z melden an D9, D10 und D12. Der Laser
bekommt seine Leistung als PWM von D11. Ein Spannungsteiler an den 24 V
meldet an A0 (Abort), wenn sie fehlen.

Kein 230 V in der Maschine: Das Steckernetzteil liefert 24 V, am Rahmen
muss nichts geerdet werden. Eine Sicherung braucht es nicht, das Netzteil
begrenzt den Strom selbst.

## Leitungen

<!-- tabelle:leitungen -->
| Nr | Leitung | Litze | Weg | Länge | kaufen | Kette |
|---|---|---|---|---|---|---|
| W1 | **Eingang** | 0,75 mm² (AWG 18) | im Kasten | ≈ 0,15 m je Ader | Rolle | — |
| W2 | **Not-Aus-Kreis** — beide Adern führen +24 V: an beiden Enden rot markieren; NO bleibt frei | 2 × 0,75 mm² (AWG 18) | vorn raus, Kanal, Rückseite hinteres 2060, untere Nut außen am rechten 2040 nach vorn, obere Nut vorn am 2060 zum Gehäuse | 1,01 m | **1,5 m** | — |
| W3 | **Shield** | 0,75 mm² (AWG 18) | im Kasten | ≈ 0,15 m je Ader | Rolle | — |
| W4 | **Wandler-Eingang** | 0,75 mm² (AWG 18) | im Kasten | ≈ 0,15 m je Ader | Rolle | — |
| W5 | **Lüfter 24 V** — Litze dünner als 0,14 mm²: abisoliert doppelt legen | Litze des Lüfters | im Kasten, durch die Öffnung im Deckel | — | — | — |
| W6 | **5 V für die Lichtschranken** | 0,25 mm² (AWG 24) | im Kasten | ≈ 0,15 m je Ader | Rolle | — |
| W7 | **Laser** | 3 Silikonlitzen 0,34 mm² (AWG 22) | links raus, untere Nut außen am linken 2040, hinten in die Y-Kette, hinter dem Schlitten in die obere Nut des Rohrs, am Kabelflügel hoch in die X-Kette, Trägerplatte | 1,57 m | **2 m** | Y + X |
| W8 | **Pull-down 10 kΩ** — hält den Laser aus, solange der Uno startet oder ohne USB ist | Widerstand | auf dem Shield | — | — | — |
| W9 | **Lichtschranke X** | 3 Silikonlitzen 0,25 mm² (AWG 24) | links raus, untere Nut außen am linken 2040, Y-Kette, hinter dem Schlitten über das Rohr nach vorn zum Halter X | 0,83 m | **1 m** | Y |
| W10 | **Lichtschranke Y** | 3 × 0,25 mm² (AWG 24) | vorn raus, Kanal, Rückseite hinteres 2060, untere Nut außen am rechten 2040 nach hinten | 0,49 m | **1 m** | — |
| W11 | **Lichtschranke Z** | 3 Silikonlitzen 0,25 mm² (AWG 24) | wie W7 bis zur Trägerplatte, dann zum Halter am Toolhead | 1,45 m | **2 m** | Y + X |
| W12 | **X-Motor** — in der Kette nur die losen Adern, ohne Schlauch | 4 × 0,2 mm² (AWG 24) | links raus, untere Nut außen am linken 2040, Y-Kette, hinter dem Motorhalter hoch zum Motor | 0,81 m | mitgeliefert (1 m) | Y |
| W13 | **Y-Motor links** | 4 × 0,2 mm² (AWG 24) | links raus, untere Nut außen am linken 2040 nach vorn; in den Kabelhaltern unter den Wänden der drei Träger der Wanne Y durch | 0,71 m | mitgeliefert (1 m) | — |
| W14 | **Y-Motor rechts** — Spule A getauscht: dreht gegen den linken | 4 × 0,2 mm² (AWG 24) | vorn raus, Kanal, Rückseite hinteres 2060, untere Nut außen am rechten 2040 nach vorn | 0,98 m | **1,5 m**, fertig | — |
| W15 | **Z-Motor** — in den Ketten nur die losen Adern, ohne Schlauch | 4 × 0,2 mm² (AWG 24) | wie W7 bis zur Trägerplatte, dann zum Motor oben | 1,54 m | **2 m**, fertig | Y + X |
| W16 | **24-V-Wächter an Abort** — fehlen die 24 V hinter Schalter und Not-Aus, bricht GRBL ab | Widerstand | im Kasten | — | — | — |
| W17 | **USB zum Pi** — Micro-B in die Buchse „USB“ des Pi, nicht in „PWR IN“ | USB-Kabel Micro-B–B (OTG) | hinten aus dem USB-Fenster, hinter dem Kasten nach rechts, an seiner rechten Wand nach vorn zum Pi-Halter | 0,44 m | **1 m**, fertig | — |
| W18 | **24 V für den Pi** — vor Schalter und Not-Aus: Pi und Uno bleiben an | 2 × 0,75 mm² (AWG 18) | an der Buchse gelötet, vorn raus, Kanal, an der Rückseite des hinteren 2060 unter dem Pi-Halter durch, von unten in die Haube und an ihrer linken Wand hoch zum 5-V-Wandler | 0,28 m | **0,5 m** | — |
| W19 | **5 V für den Pi** — Stromadern mindestens AWG 24, sonst meldet der Pi Unterspannung | USB-Kabel A–Micro-B | am Pi-Halter: vom USB-Ausgang des Wandlers in „PWR IN“ | 0,07 m | **0,25 m**, fertig | — |
<!-- /tabelle:leitungen -->

„Länge“ ist der Weg wie in [elektronik-platz.svg](elektronik-platz.svg)
gezeichnet, „kaufen“ dieser Weg plus 15 % und aufgerundet. Was übrig ist,
bleibt als Schlaufe beim Gehäuse. Die Motorfarben sind die übliche Belegung
von Stepperonline `[w]`: A+ schwarz, A− grün, B+ rot, B− blau. Am Stecker ab
Werk liegen sie schwarz · grün · blau · rot `[v]` (außen schwarz und rot),
also A+ · A− · B− · B+. Vor dem Anschließen mit dem Ohmmeter prüfen
([Motoren](#6-motoren-w12w15)).

## Anschlussliste

<!-- tabelle:anschluesse -->
| Nr | Ader | Farbe | von | an |
|---|---|---|---|---|
| W1 | +24 V | rot | Einbaubuchse, Mittelstift (+) | Schalter, Kontakt 1 |
|  | GND | schwarz | Einbaubuchse, Hülse (−) | Wago GND |
| W2 | +24 V hin | Ader 1 | Schalter, Kontakt 2 | Not-Aus, C |
|  | +24 V zurück | Ader 2 | Not-Aus, NC | Wago +24 V |
| W3 | +24 V | rot | Wago +24 V | Shield, Schraubklemme + |
|  | GND | schwarz | Wago GND | Shield, Schraubklemme − |
| W4 | +24 V | rot | Wago +24 V | Wandler IN+ |
|  | GND | schwarz | Wago GND | Wandler IN− |
| W5 | +24 V | rot | Lüfter, rote Litze | Wago +24 V |
|  | GND | schwarz | Lüfter, schwarze Litze | Wago GND |
| W6 | +5 V | rot | Shield, Stift 5V | Wago +5 V |
| W7 | +12 V | rot | Wandler OUT+ | Laser, XH rechts: +12 V |
|  | GND | schwarz | Wandler OUT− | Laser, XH Mitte: GND |
|  | PWM | weiß | Shield Z+ (D11), Signalstift | Laser, XH links: PWM |
| W8 | 10 kΩ | — | Shield Z− (D11), Signalstift | Shield Z−, GND-Stift |
| W9 | +5 V | rot | Wago +5 V | Lichtschranke X, VCC |
|  | GND | schwarz | Wago GND | Lichtschranke X, GND |
|  | Signal | gelb | Shield X− (D9), Signalstift | Lichtschranke X, D0 |
| W10 | +5 V | rot | Wago +5 V | Lichtschranke Y, VCC |
|  | GND | schwarz | Wago GND | Lichtschranke Y, GND |
|  | Signal | gelb | Shield Y+ (D10), Signalstift | Lichtschranke Y, D0 |
| W11 | +5 V | rot | Wago +5 V | Lichtschranke Z, VCC |
|  | GND | schwarz | Wago GND | Lichtschranke Z, GND |
|  | Signal | gelb | Shield SpnEn (D12) | Lichtschranke Z, D0 |
| W12 | Spule A | schwarz · grün | Shield Motor X, 2B · 2A | X-Motor, Spule A: A+ · A− |
|  | Spule B | blau · rot | Shield Motor X, 1A · 1B | X-Motor, Spule B: B− · B+ |
| W13 | Spule A | schwarz · grün | Shield Motor Y, 2B · 2A | Y-Motor links, Spule A: A+ · A− |
|  | Spule B | blau · rot | Shield Motor Y, 1A · 1B | Y-Motor links, Spule B: B− · B+ |
| W14 | Spule A, getauscht | grün · schwarz | Shield Motor A, 2B · 2A | Y-Motor rechts, Spule A: A− · A+ |
|  | Spule B | blau · rot | Shield Motor A, 1A · 1B | Y-Motor rechts, Spule B: B− · B+ |
| W15 | Spule A | schwarz · grün | Shield Motor Z, 2B · 2A | Z-Motor, Spule A: A+ · A− |
|  | Spule B | blau · rot | Shield Motor Z, 1A · 1B | Z-Motor, Spule B: B− · B+ |
| W16 | R1 22 kΩ | — | Wago +24 V | Shield Abort (A0) |
|  | R2 4,7 kΩ ∥ 100 nF | — | Shield Abort (A0) | Wago GND |
| W17 | USB | — | Uno, USB-B | Pi, Micro-USB „USB“ |
| W18 | +24 V | rot | Einbaubuchse, Mittelstift (+) | 5-V-Wandler IN+ |
|  | GND | schwarz | Einbaubuchse, Hülse (−) | 5-V-Wandler IN− |
| W19 | 5 V | — | 5-V-Wandler, USB-A | Pi, Micro-USB „PWR IN“ |
<!-- /tabelle:anschluesse -->

## Klemmen: Wago und Shield

<!-- tabelle:wago -->
| Klemme | Typ | belegt | frei | angeschlossen |
|---|---|---|---|---|
| **Wago +24 V** | 221-415 | 5 von 5 | 0 | W2 Not-Aus, NC · W3 Shield, Schraubklemme + · W4 Wandler IN+ · W5 Lüfter, rote Litze · W16 Shield Abort (A0) |
| **Wago GND** | 221-420 | 8 von 10 | 2 (einer davon für OUT− eines isolierten Wandlers) | W1 Einbaubuchse, Hülse (−) · W3 Shield, Schraubklemme − · W4 Wandler IN− · W5 Lüfter, schwarze Litze · W9 Lichtschranke X, GND · W10 Lichtschranke Y, GND · W11 Lichtschranke Z, GND · W16 Shield Abort (A0) |
| **Wago +5 V** | 221-420 | 4 von 10 | 6 | W6 Shield, Stift 5V · W9 Lichtschranke X, VCC · W10 Lichtschranke Y, VCC · W11 Lichtschranke Z, VCC |
<!-- /tabelle:wago -->

<!-- tabelle:shield -->
| Stift | Uno-Pin | Aufgabe | angeschlossen |
|---|---|---|---|
| Schraubklemme + | — | 24 V für die Treiber (12–36 V) | W3 → Wago +24 V |
| Schraubklemme − | — | GND | W3 → Wago GND |
| Stift 5V | 5 V | Versorgung der Lichtschranken (vom USB des Uno) | W6 → Wago +5 V |
| X− (D9), Signalstift | D9 | Endschalter X (X+ ist derselbe Pin) | W9 → Lichtschranke X, D0 |
| Y+ (D10), Signalstift | D10 | Endschalter Y (Y− ist derselbe Pin) | W10 → Lichtschranke Y, D0 |
| SpnEn (D12) | D12 | Endschalter Z — GRBL 1.1 legt ihn auf D12 | W11 → Lichtschranke Z, D0 |
| Z+ (D11), Signalstift | D11 | Laser-PWM — kein Endschalter | W7 → Laser, XH links: PWM |
| Z− (D11), Signalstift | D11 | Pull-down 10 kΩ zum GND-Stift daneben | W8 → Shield Z−, GND-Stift |
| Abort (A0) | A0 | 24-V-Wächter: ohne 24 V bricht GRBL ab | W16 → Wago +24 V · W16 → Wago GND |
| Motor X, Y, Z, A | — | 2B · 2A · 1A · 1B je Treiber; A klont Y (Jumper) | W12 · W13 · W15 · W14 |
<!-- /tabelle:shield -->

* Auf dem Shield liegen **X+ und X− auf demselben Pin** (D9), ebenso Y+/Y−
  (D10) und Z+/Z− (D11). Stecken nur dort, wo die Tabelle es sagt: An
  Z+/Z− liegt die Laser-PWM, das ist ein Ausgang.
* Die Masse der Lichtschranken geht an die Wago GND, nicht an einen
  GND-Stift am Shield. So muss niemand GND-Stifte suchen, und neben SpnEn
  gibt es womöglich keinen.
* **Jumper:** MS1 + MS2 an allen vier Treibern (1/16), MS3 frei. A klont
  Y: A.STEP ↔ Y.STEP und A.DIR ↔ Y.DIR. Die Jumper **D12/D13 für A nicht
  stecken**, denn D12 ist der Z-Endschalter. EN/GND bleibt offen, GRBL
  schaltet die Treiber über D8.
* **Treiber** mit dem EN-Pin zum EN-Aufdruck stecken.

## Material und Werkzeug

<!-- tabelle:material -->
| Menge | Teil | für |
|---|---|---|
| 0,5 m | Einzelader 0,75 mm² (AWG 18), rot | W1 0,15 m · W3 0,15 m · W4 0,15 m |
| 0,5 m | Einzelader 0,75 mm² (AWG 18), schwarz | W1 0,15 m · W3 0,15 m · W4 0,15 m |
| 2 m | 2 × 0,75 mm² (AWG 18) | W2 1,5 m · W18 0,5 m |
| 1,5 m | 3 × 0,25 mm² (AWG 24) | W6 0,15 m · W10 1 m |
| 2 m | Silikonlitze 0,34 mm² (AWG 22), rot | W7 2 m |
| 2 m | Silikonlitze 0,34 mm² (AWG 22), schwarz | W7 2 m |
| 2 m | Silikonlitze 0,34 mm² (AWG 22), weiß | W7 2 m |
| 3 m | Silikonlitze 0,25 mm² (AWG 24), rot | W9 1 m · W11 2 m |
| 3 m | Silikonlitze 0,25 mm² (AWG 24), schwarz | W9 1 m · W11 2 m |
| 3 m | Silikonlitze 0,25 mm² (AWG 24), gelb | W9 1 m · W11 2 m |
| 1 + 1 | Motorkabel 1,5 m und 2 m, 4 × AWG 24, PH-Stecker zum Motor, Dupont 4-polig zum Shield; für W15 lose Adern ohne Mantel (läuft durch beide Ketten) | W14, W15 (W12, W13: die mitgelieferten 1-m-Kabel) |
| 1 | USB-Kabel Micro-B–B (OTG), 1 m | W17 (USB zum Pi) |
| 1 | USB-Kabel A–Micro-B, 0,25 m | W19 (5 V für den Pi) |
| 17 + Reserve | Dupont-Crimpkontakte (Buchse) | Shield, Lichtschranken, W8, W16 |
| 6 · 1 · 3 | Dupont-Gehäuse 1-, 2- und 3-polig | Shield, Pull-down, Lichtschranken |
| 1 + 3 | XH2.54-Gehäuse 3-polig + Crimpkontakte | Laser |
| 2 | Aderendhülse 0,34 mm² | Schraubklemmen |
| 6 | Aderendhülse 0,75 mm² | Schraubklemmen |
| 1 | Widerstand 10 kΩ, ¼ W | W8 |
| 1 + 1 + 1 | Widerstand 22 kΩ und 4,7 kΩ, ¼ W; Kondensator 100 nF | W16 |
| — | Not-Aus-Pilztaster 16 mm, Wechsler C/NO/NC, 3 A / 250 V (vorhanden), Gehäuse aus [NotAus.py](notaus.md) | W2 |
| — | Schrumpfschlauch 2–6 mm, Kabelbinder, Beschriftung (W-Nummer an beiden Enden) | alle |
<!-- /tabelle:material -->

* **Litze:** in den Ketten nur Einzellitzen aus Silikon, keine
  Mantelleitungen: Die gedruckten Ketten biegen mit R 20
  ([energiekette.md](energiekette.md#litzen-in-der-kette)). Für die
  Signale 0,25 mm²: Das hält sicher in der
  Wago (ab 0,14 mm²), und in den Dupont-Kontakt passen bis 0,34 mm². Ist
  schon Litze mit 0,14 mm² oder AWG 26 (0,13 mm²) da, geht sie auch: in
  der Wago das abisolierte Ende doppelt legen.
* **Werkzeug:** Crimpzange für Dupont und XH (2,54 mm, z. B. SN-28B),
  Zange für Aderendhülsen, Abisolierzange, Lötkolben, Multimeter mit
  Durchgangsprüfer, Schrumpfschlauch.
* **Wago 221:** 11 mm abisolieren, Hebel auf, Litze bis zum Anschlag, Hebel
  zu. Ohne Aderendhülse.
* **Schraubklemmen** (Shield, Wandler): immer mit Aderendhülse.
  Verzinnte Litze gibt in der Klemme mit der Zeit nach.
* **Dupont und XH:** 2 mm abisolieren, crimpen, an jedem Kontakt ziehen.
  Die Kontakte rasten im Gehäuse hörbar ein.

## Schritt für Schritt

Zuerst alles im Gehäuse, dann nach außen zur Maschine. Die Prüfungen der
[Inbetriebnahme](#inbetriebnahme) gehören jeweils dazwischen.

Verkabelung Schritt für Schritt

Das Bild zeigt jeden der acht Schritte für sich: jede Ader von Klemme zu
Klemme in ihrer Farbe aus der [Anschlussliste](#anschlussliste), die
Wago-Plätze in der Reihenfolge der Tabelle
[Klemmen](#klemmen-wago-und-shield), und welche Prüfung danach kommt. Oben
die Leitungen, die das Gehäuse verlassen, mit ihren Wegen. Das Bild entsteht
aus derselben Kabelliste und bricht ab, wenn eine Ader fehlt, doppelt oder
im falschen Schritt gezeichnet ist.

### 1. Vorbereiten

* Die Leitungen nach der Tabelle ablängen und an beiden Enden mit der
  W-Nummer beschriften.
* Einbaubuchse und Schalter hinten ins Gehäuse setzen (Mutter innen,
  Schalter rastet ein), die Wago-Klemmen mit Klebeband auf ihren Platz:
  von links **+5 V**, **GND**, **+24 V**.
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

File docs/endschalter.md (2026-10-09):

# Endschalter X und Y — Halter und Schaltfahnen

Die fünf Druckteile und die ausgeblendete Bohrlehre der Lichtschranke
erzeugt `fusion/Portal/Portal.py` (seit Rev. 15, jetzt Rev. 28) als eigene Komponenten der
Portal-Baugruppe, neben Schlitten, Klemmtürmen und Antrieben. Bis Portal
Rev. 14 standen sie im eigenen Skript `Endschalter.py`; Maße und Lagen sind
dieselben. Geprüft mit `python3 tools/endschalter_check.py`, Skizze in
[endschalter.svg](endschalter.svg) (neu erzeugen mit
`python3 tools/endschalter_zeichnen.py`).

Endschalter X und Y

## Was wo sitzt

Beide Achsen bekommen eine **LM393-Gabellichtschranke** wie Z (Maße in
[hardware-notizen.md](hardware-notizen.md#endschalter)). Warum Y rechts
hinten und X links, steht in [elektronik.md](elektronik.md#endschalter).
Deine Angaben vom 2026-09-29: Halter und Fahnen bauen, die Winkel an den
Kreuzungen sind 20 mm groß, die Nuten sind frei, und eine Klammer an der
Trägerplatte ist in Ordnung.
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

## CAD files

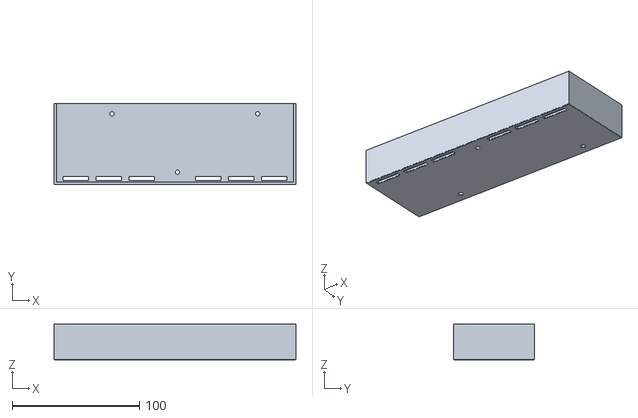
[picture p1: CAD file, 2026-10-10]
stl/PiHalter_Haube_r3.stl
190.0 x 63.4 x 28.0

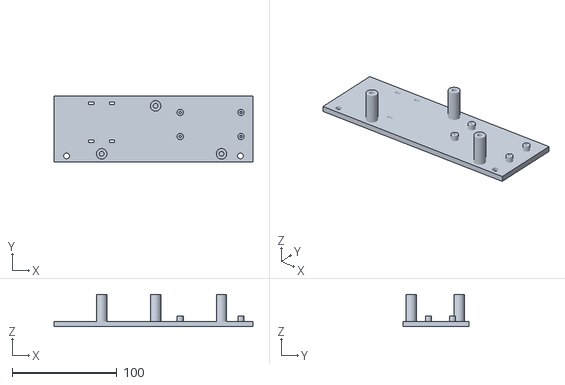
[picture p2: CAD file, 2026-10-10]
stl/PiHalter_r3.stl
190.0 x 63.4 x 30.7

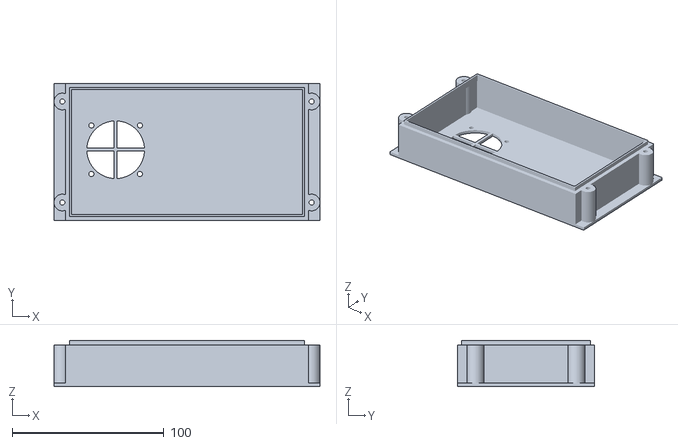
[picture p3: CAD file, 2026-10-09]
stl/Elektronik_Deckel_r4.stl
175.3 x 90.6 x 30.5

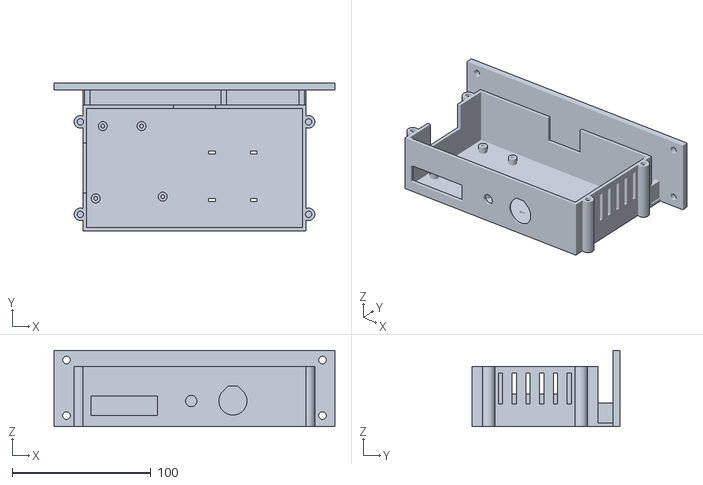
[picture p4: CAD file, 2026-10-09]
stl/Elektronik_Gehaeuse_r4.stl
202.3 x 106.6 x 55.0

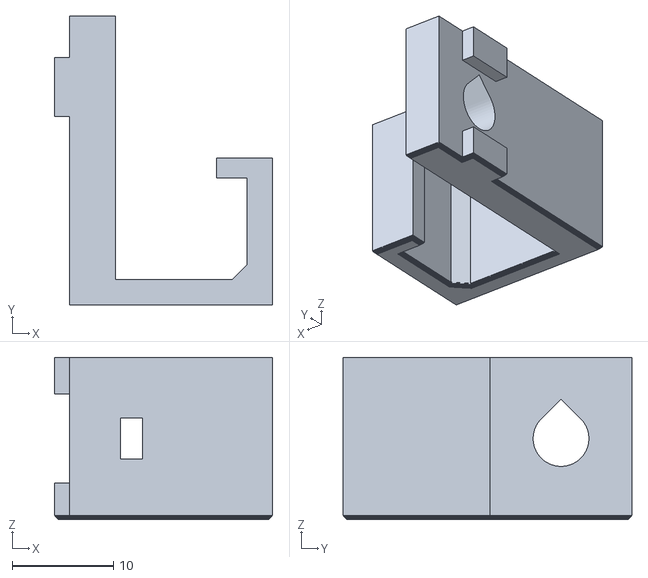
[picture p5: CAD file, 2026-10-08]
stl/Kabelhalter_r2.stl
21.5 x 28.5 x 16.0

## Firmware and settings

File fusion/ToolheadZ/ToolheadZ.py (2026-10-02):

# ToolheadZ.py — kompletter Laser-Toolhead mit NEMA17-Z-Achse
#
# Baugruppe (acht gedruckte Teile), weil sich Teile relativ zueinander bewegen:
#   Traegerplatte   — geerdet, sitzt auf dem MGN15H-Wagen der Portalfuehrung,
#                     traegt die MGN9-Z-Schiene (Sockel) und die angeformte
#                     Motorkonsole
#   Motoradapter    — Distanzplatte zwischen Konsole und NEMA 17 (Welle nach
#                     unten); hebt den Motor, ohne die Traegerplatte zu aendern
#   Schlittenplatte — auf dem MGN9H-Z-Wagen, traegt den Diodenlaser
#   Mutternwinkel   — Winkel fuer die Tr8x2-Anti-Backlash-Garnitur: Regal
#                     ueber der Plattenoberkante, Ruecken schwimmend an der
#                     Schlittenplatte verschraubt
#   Endschalterhalter — traegt die Gabellichtschranke am Sockel der Platte
#   Schaltfahne     — duennes schwarzes Blatt fuer die Gabel, an einer Lasche
#                     links an der Schlittenplatte verschraubt
#   Riemenhalter    — klemmt beide Enden des X-Riemens, hinten an der
#                     Traegerplatte ueber dem X-Wagen (Motor und Umlenkung
#                     sitzen auf den Y-Schlitten, fusion/Portal)
#   Kettenhalter    — hinten an der Traegerplatte ueber dem Riemenhalter
#                     (Rev. 35): traegt das Anfangsstueck der gedruckten
#                     X-Energiekette; Wanne und Festpunkt in fusion/Portal
#
# Koordinatensystem = Maschinenkoordinaten, global fuer alle Komponenten:
#   X = quer, laengs des Portals          Y = nach vorn, weg vom Portal
#   Z = senkrecht (Verfahrrichtung Z)     Ursprung = Mitte des X-Wagen-
#   Lochbildes AUF seiner Stirnflaeche (die Passflaeche der Traegerplatte).
#
# Alle Ebenen und Achsen leitet `lage()` aus MASSE ab — eine Quelle fuer
# Geometrie und fuer die Pruefung in tools/toolhead_check.py.
#
# Konventionen: siehe fusion-python/SKILL.md und references/baugruppen.md.

import math

import adsk.core, adsk.fusion, traceback

SKRIPT_NAME = 'ToolheadZ'
REVISION = 38

# --- Masse (einzige Quelle; erzeugt 1:1 die Fusion-User-Parameter) -----------
# Name: (Wert in mm, Kommentar fuer den Parameter-Dialog)
MASSE = {
    # --- Kaufteil: Portalfuehrung MGN15H ------------------------------------
    # quer = senkrecht zur Schiene = Z, laengs = laengs der Schiene = X
    # Das Lochbild 25 x 25 ist am 2026-09-21 mit Bohrlehre_XWagen am Wagen
    # geprueft und bestaetigt [v] — damit ist es ein MGN15H (ein MGN15C
    # haette 25 x 20) und die alte Messung "26 x 25" ist widerlegt: bei
    # Ø3,4-Lochlehre auf M3 wuerde 1 mm Abweichung nicht mehr passen.
    'x_wagen_loch_quer':   (25.0,  'MGN15H Wagen: Lochabstand in Z'),
    'x_wagen_loch_laengs': (25.0,  'MGN15H Wagen: Lochabstand in X'),
    'x_wagen_breite':      (32.0,  'MGN15H Wagen: Breite (in Z)'),
    'x_wagen_laenge':      (58.8,  'MGN15H Wagen: Laenge (in X)'),
    'x_wagen_hoehe':       (16.0,  'MGN15 Montagehoehe: Wagenflaeche ueber Profil'),
    'x_schiene_hoehe':     (10.0,  'MGN15 Schiene: Hoehe'),
    'x_gewinde_tiefe':     (4.0,   'MGN15 Wagen: M3-Gewindetiefe'),

    # --- Kaufteil: Z-Fuehrung MGN9H (hardware.md [w]) ----------------------
    # quer = X, laengs = Z (Schiene steht senkrecht)
    'z_wagen_loch_quer':   (15.0,  'MGN9H Wagen: Lochabstand in X'),
    'z_wagen_loch_laengs': (16.0,  'MGN9H Wagen: Lochabstand in Z'),
    'z_wagen_breite':      (20.0,  'MGN9H Wagen: Breite (in X)'),
    'z_wagen_laenge':      (39.9,  'MGN9H Wagen: Laenge (in Z)'),
    'z_wagen_hoehe':       (10.0,  'MGN9 Montagehoehe: Wagenflaeche ueber Sockel'),
    'z_schiene_breite':    (9.0,   'MGN9 Schiene: Breite'),
    'z_schiene_hoehe':     (6.5,   'MGN9 Schiene: Hoehe'),
    # 200 mm ist die vorhandene Schiene [v]; 10 + 9*20 + 10 = 200, also
    # 10 Loecher. Die Schiene sitzt in Z FEST (sie haengt am X-Wagen), ihr
    # unteres Ende ist damit ein dauerhaftes Hindernis: es muss ueber dem
    # dicksten Werkstueck bleiben. Deshalb waechst sie nach OBEN, nicht nach
    # unten — Unterkante bleibt, wo sie war.
    'z_schiene_laenge':   (200.0,  'MGN9 Schiene: Laenge (10 + 9*20 + 10)'),
    'z_schiene_lochab':    (20.0,  'MGN9 Schiene: Lochabstand'),
    'z_schiene_randab':    (10.0,  'MGN9 Schiene: Randabstand'),
    'z_schiene_senkung':   (3.3,   'MGN9 Schiene: Tiefe der Senkung'),
    'z_gewinde_tiefe':     (2.5,   'MGN9 Wagen: M3-Gewindetiefe'),

    # --- Kaufteil: NEMA 17 (hardware.md [w]) -------------------------------
    'motor_flansch':       (42.3,  'NEMA17: Flanschmass'),
    'motor_loch':          (31.0,  'NEMA17: Lochbild 31 x 31'),
    'motor_bund_d':        (22.0,  'NEMA17: Zentrierbund Durchmesser'),
    'motor_bund_h':        (2.0,   'NEMA17: Zentrierbund Hoehe'),
    'motor_welle_l':       (24.0,  'NEMA17: Wellenlaenge'),
    'motor_laenge':        (40.0,  'NEMA17: Koerperlaenge (nur Freigang)'),
    # Die Motorschraube darf im Flanschgewinde nicht aufsetzen, sonst klemmt
    # sie nichts. Ueblich sind 4,5 mm Gewindetiefe [w].
    'motor_gewinde_tiefe':  (4.5,  'NEMA17: Gewindetiefe im Flansch'),
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

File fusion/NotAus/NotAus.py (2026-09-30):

# NotAus.py — Gehaeuse fuer den Not-Aus vorn am vorderen 2060
#
# Ein Druckteil, dazu Referenzteile nur zur Ansicht:
#   Gehaeuse_NotAus  offener Kasten vor der Vorderseite des vorderen 2060,
#               rechts innen neben dem rechten 2040. Die Frontwand traegt den
#               Pilztaster (Gewinde durch, Mutter innen), die Rueckseite ist
#               offen und liegt am 2060 an. Links und rechts eine Lasche mit
#               M5 in einer Hammermutter der mittleren Nut; laengs der Nut
#               laesst sich das Gehaeuse verschieben. Zwei 45-Grad-Rippen an
#               den Kanten jeder Lasche tragen sie beim Druck (Front aufs
#               Bett) und lassen Schraube, Scheibe und Inbus frei. Rechts
#               oben der Kabeldurchlass, davor und dahinter je ein Schlitz
#               fuer einen Kabelbinder (Zugentlastung).
#   Referenz_nicht_drucken  vorderes 2060, rechtes 2040 vorn, Y-Motorhalter
#               und Motor rechts (als Huelle, wie in Portal.py) und der
#               Taster.
#
# Der Taster [v] (Bild und Angaben vom 2026-09-30): Pilzkopf, rastet beim
# Druecken ein, Drehen loest; ein Wechsler C, NO, NC mit Loetfahnen,
# 3 A / 250 V; Gewinde 16 mm, rund ohne Abflachung: gegen Verdrehen haelt
# ihn nur die Mutter. Verdrahtet wird C und NC (Oeffner) in der
# 24-V-Leitung, NO bleibt frei (docs/verkabelung.md). Kopf, Tiefe und
# Mutter sind nicht gemessen [?]: sie dienen nur der Referenz und der
# Pruefung, das Gehaeuse hat Reserve.
#
# Koordinaten = Maschinenkoordinaten wie Portal.py: X nach rechts, Y nach
# vorn, Z senkrecht, Z = 0 in der Mitte des Portalrohrs. Im Fusion-Modell
# sind Y und Z getauscht (Modell-Z = Maschine Y). tools/notaus_check.py
# vergleicht die Rahmenmasse und den Y-Motorhalter mit Portal.py.
#
# Konventionen: siehe fusion-python/SKILL.md und references/baugruppen.md.

import adsk.core, adsk.fusion, traceback

SKRIPT_NAME = 'NotAus'
REVISION = 5

# --- Masse (einzige Quelle; erzeugt 1:1 die Fusion-User-Parameter) -----------
# Name: (Wert in mm, Kommentar fuer den Parameter-Dialog)
MASSE = {
    # --- Rahmen (wie Portal.py) [v] -----------------------------------------
    'y_schienen_abstand': (514.0, 'Y-Schienen: Abstand Mitte zu Mitte'),
    'rahmen_b':            (20.0, 'Rahmen 2040 hochkant: Breite'),
    'rahmen_h':            (40.0, 'Rahmen 2040 hochkant: Hoehe'),
    'rahmen_y1':          (240.0, 'Rahmen: vordere Stirnseite der 2040'),
    'rahmen_z0':          (-69.0, 'Rahmen: Unterkante der 2040 = Oberkante 2060'),
    'quer_y0':            (185.0, 'vorderes 2060: Rueckseite'),
    'quer_h':              (60.0, '2060 quer, hochkant: Hoehe'),
    'nut_mitte':           (10.0, 'Profil: Nutmitte 10 mm von der Kante'),
    # V-Slot vereinfacht (Referenz), wie Portal.py
    'nut_oben':             (6.0, 'V-Slot: Oberkante der Nutoeffnung unter der Kante'),
    'nut_v_t':              (1.0, 'V-Slot vereinfacht: Tiefe des V aussen'),
    'nut_b':                (6.2, 'V-Slot: Nutoeffnung innen (Engstelle)'),
    'nut_t':                (2.0, 'V-Slot vereinfacht: Tiefe der Engstelle'),
    'nut_kammer_b':         (8.0, 'V-Slot vereinfacht: Breite der Kammer'),
    'nut_kammer_t':         (5.5, 'V-Slot vereinfacht: Tiefe bis Kammergrund'),
    'kern_d':               (4.2, 'V-Slot: Kernbohrung'),

    # --- Y-Motorhalter rechts, Huelle (wie in Portal.py) [v] ----------------
    # Y ab der Stirnseite der 2040, Z ab ihrer Unterkante, X ab ihrer Mitte
    'ymh_halbe_b':        (26.15, 'Y-Motorhalter: halbe Breite'),
    'ymh_y0':             (-30.0, 'Y-Motorhalter: Schenkel hinten'),
    'ymh_y1':              (56.8, 'Y-Motorhalter: Platte vorn'),
    'ymh_z0':               (1.0, 'Y-Motorhalter: unten'),
    'ymh_z1':              (17.5, 'Y-Motorhalter: oben'),
    'motor_b':             (42.3, 'NEMA 17: Flansch'),
    'motor_y_min':        (26.15, 'Motorachse ganz innen'),
    'motor_y_max':        (34.15, 'Motorachse ganz aussen'),
    'motor_z0':           (-25.5, 'Motor unten'),
    'motor_z1':            (11.5, 'Motorflansch = Platte unten'),

    # --- Taster (Pilzkopf, Wechsler C/NO/NC) --------------------------------
    # Rev. 2: Gewinde 16 mm [v] Angabe 2026-09-30 (Rev. 1: 19 mm angenommen).
    # Rev. 3: nur der Bericht; das Gewinde ist rund [v], das Loch bleibt.
    # Rev. 4: nur ein Kommentar (die Endschalter stehen jetzt in Portal.py).
    # Rev. 5: der Y-Motorhalter steht jetzt in Portal.py (Kommentare, und
    #        der Referenzkoerper heisst wie dort Y-Motorhalter_rechts).
    # Kopf, Tiefe, Mutter und Klemmbereich sind nicht gemessen [?].
    'schalter_d':          (16.0, 'Not-Aus: Gewindedurchmesser [v] Angabe'),
    'schalter_spiel':       (0.3, 'Loch so viel groesser als das Gewinde'),
    'schalter_kopf_d':     (32.0, 'Not-Aus: Pilzkopf [?]'),
    'schalter_kopf_h':     (22.0, 'Not-Aus: Kopf vor der Frontwand [?]'),
    'schalter_tiefe':      (30.0, 'Not-Aus: hinter der Frontwand mit Loetfahnen [?]'),
    'schalter_mutter':     (24.0, 'Not-Aus: Mutter ueber Eck [?]'),
    'klemm_max':            (6.0, 'Not-Aus: so dick darf die Wand sein [?]'),
    'draht_biegen':        (10.0, 'hinter den Loetfahnen fuer die Litze'),

    # --- Gehaeuse -----------------------------------------------------------
    # rechts innen neben dem rechten 2040, gut mit der rechten Hand; laengs der
    # mittleren Nut verschiebbar
    'na_x':               (180.0, 'Gehaeuse: Mitte in X'),
    'na_b':                (50.0, 'Gehaeuse: Breite (X)'),
    'na_h':                (50.0, 'Gehaeuse: Hoehe (Z)'),
    'na_t':                (46.0, 'Gehaeuse: Tiefe vor dem 2060 (Y)'),
    'na_wand':              (3.0, 'Gehaeuse: Seiten, oben, unten'),
    'na_front':             (3.0, 'Gehaeuse: Frontwand, der Taster klemmt darauf'),
    'lasche_b':            (14.0, 'Lasche: neben dem Gehaeuse (X)'),
    'lasche_h':            (20.0, 'Lasche: Hoehe (Z)'),
    'lasche_t':             (6.0, 'Lasche: Dicke an der Anlage (Y)'),
    'rippe_d':              (3.0, 'Rippe an der Laschenkante: Dicke (Z)'),
    'kabel_d':              (7.0, 'Kabeldurchlass (2 x 0,75 mm2, aussen ~6)'),
    'kabel_z_oben':         (8.0, 'Kabeldurchlass: Mitte so weit unter der Oberkante'),
    'kabel_y':             (14.0, 'Kabeldurchlass: Mitte so weit vor dem 2060'),
    'binder_b':             (4.5, 'Schlitz fuer den Kabelbinder (Z)'),
    'binder_t':             (2.5, 'Schlitz fuer den Kabelbinder (Y)'),
    'binder_abstand':       (9.0, 'Schlitze so weit vor und hinter dem Durchlass'),

    # --- Normteile und Regeln ------------------------------------------------
    'm5_durchgang':         (5.5, 'M5 Durchgang'),
    'm5_scheibe_d':        (10.0, 'M5 Scheibe DIN 125: Durchmesser'),
    'm5_scheibe_h':         (1.0, 'M5 Scheibe DIN 125: Dicke'),
    'm5_kopf_h':            (5.0, 'M5 Zylinderkopf: Hoehe'),
    'luft_bau':             (3.0, 'Mindestfreigang'),
    'fase_fuss':            (0.4, 'Fase gegen Elefantenfuss'),
}
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

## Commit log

2026-09-16 Toolhead-Grundplatte fuer den Diodenlaser der Z-Achse
    Fusion-Skript fuer die Grundplatte des Laser-Toolheads, aufgebaut als
    Versatzplatte statt als flache Platte: ein 6 mm hohes Auflagepad setzt die
    Platte von der Stirnflaeche des MGN9-Wagens ab, die Laser-Anschraubflaeche
    liegt 12 mm davor. Damit steckt die Montagehoehe des Wagens (10 mm) explizit
    in der Masskette — sie war die Ursache dafuer, dass die erste Platte nicht
    buendig sass. Der Modellursprung liegt auf genau dieser Passflaeche.
    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
2026-09-16 Kompletter Laser-Toolhead mit NEMA17-Z-Achse als Baugruppe
    Die Einzelplatte deckte nur den Laser ab, nicht die Achse. ToolheadZ baut den
    ganzen Toolhead: Traegerplatte am MGN15H-Wagen des Portals, MGN9-Z-Fuehrung auf
    einem Schienensockel, NEMA 17 auf einer U-Konsole, flexible Kupplung auf die
    vorhandene M6-Gewindestange, Schlittenplatte mit dem Diodenlaser und ein
    Mutternblock. Bezugsebene bleibt die Passflaeche des tragenden Wagens.
    Vier gedruckte Teile (PETG), Baugruppe statt Bauteil, weil sich die Teile
    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
2026-09-16 ToolheadZ r2: Extrusionsrichtungen und Skizzenachsen nicht mehr annehmen
    Das Skript brach beim Mutternblock ab: EXTRUDE_ZERO_DISTANCE_ERROR an der
    Spindelbohrung. Ursache war ein einseitiger ThroughAll-Schnitt, dessen Richtung
    an der Normale der Offset-Ebene haengt — bei der Motorkonsole zeigte sie ins
    Material, beim Mutternblock (Offset mit umgekehrtem Vorzeichen) davon weg.
    Statt das Vorzeichen zu korrigieren, sind die drei Annahmen beseitigt, auf denen
    das beruhte:
    - Offset-Ebenen messen ihre Lage nach (pl.geometry.origin) und drehen das
    Vorzeichen selbst um, wenn sie auf der falschen Seite liegen.
    - Skizzenpunkte werden mit modelToSketchSpace aus Maschinenkoordinaten
    umgerechnet,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
    [ToolheadZ.py]
2026-09-16 ToolheadZ r3: Motorkonsole an die Traegerplatte angeformt, Motor formschluessig
    Zwei der vier NEMA17-Schrauben waren nicht erreichbar. Ursache: NEMA17 hat
    Gewinde im Flansch, wird also von unten verschraubt, und die hintere
    Schraubenreihe liegt bei Y=+5,5 mitten im Querschnitt der Traegerplatte
    (Y=0..8). Die Platte ist eine durchgehende Wand ueber ihre ganze Hoehe — von
    unten kommt dort prinzipiell kein Werkzeug hin, auch nicht mit separatem
    Halter. Die Motorachse haengt an der Spindelachse, und die muss bei Y=21
    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
2026-09-16 ToolheadZ r4: alle vier Motorschrauben erreichbar (Variante V-B)
    Die Motorachse wandert von Y=21 auf Y=28,5. Damit liegt die hintere
    Schraubenreihe des NEMA 17 bei Y=+13,0 und hat 2,0 mm Luft zum Zugangskorridor
    an der Traegerplatte (Y=0..8) — alle vier Schrauben sind von unten erreichbar.
    Nach vorn begrenzt die Wand vor der Spindelbohrung im Mutternblock
    (schlitten_y1 >= spindel_y + 6,3), deshalb 28,5 und nicht mehr.
    Damit die Schlittenplatte weit genug vor der Spindelachse liegt, wird
    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
2026-09-21 Rev. 23: Mutternblock wird Mutternwinkel fuer die Tr8x2-Garnitur
    Spindel, Anti-Backlash-Garnitur und Klemmkupplung sind gekauft — die
    Spielfreiheit kommt jetzt aus dem Kaufteil. Das Druckteil liefert nur noch
    den Flanschsitz, also Winkel statt Block.
    Warum das Regal ueber der Plattenoberkante liegt: der Ø22-Flansch sitzt
    mittig auf der Spindelachse (Y=28,5) und wuerde hinter der Schlittenplatte
    (Rueckseite Y=35) 4,5 mm in die Platte laufen. Die Alternative waere
    pad_hoehe 12 -> 18 gewesen — das haette Strahlachse und Wagenschrauben
    mitgezogen. So bleibt alles andere unveraendert.
    Geometrie:
    - Ruecken 8 mm bei Y 27..35, Regal 10 mm bei Z zc+17,5..+27,5
    - Spindel laeuft mitten durch den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
    [ToolheadZ.py, bauraum.py, toolhead_check.py]
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2026-09-23 Kupplung: bestellt ist laut Titel eine starre Huelse, keine Wendelkupplung
    Rueckfrage, warum die Kupplung auf den Produktbildern kein Gewinde hat. Das
    ist richtig so — keine Kupplung hat eins, die glatte Ø8-Bohrung greift auf
    die Gewindespitzen der Spindel. "Threaded Spindle" im Titel meint die
    Spindel.
    Dabei aufgefallen: der Titel der bestellten UniTak3D 5x8 (B096G1GZH5) sagt
    "Rigid Coupling" / "Aluminum Casing" — eine starre Huelse mit seitlichen
    Madenschrauben, keine Wendelkupplung. Die Doku hatte seit Rev. 24 die
    Wendelkupplung als verbaut festgeschrieben; das war eine Annahme.
    - Doku und Skriptbericht nennen jetzt das bestellte Teil und beide
    Einbauregeln, weil sie gegensaetzli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
    [ToolheadZ.py, toolhead_check.py]
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2026-09-23 Rev. 28: Flanschring entfaellt — die glatte Flanschseite liegt auf dem Regal
    Am Teil nachgesehen: der Flansch der Anti-Backlash-Mutter ist auf einer
    Seite glatt, der Bund Ø10x2 sitzt auf der anderen. Die glatte Seite kommt
    aufs Regal, der Bund zeigt nach oben zu Feder und Gleitmutter. Damit muss
    im Regal nichts freigehalten werden, und der Flanschring aus Rev. 25-27
    (eingefuehrt, weil der Bund unten vermutet war) ist ueberfluessig.
    - Bauteil Flanschring, seine Pruefungen, Bauraum und Joint entfernt; wieder
    vier Druckteile
    - Mutternwinkel unveraendert: Regal, Spindelbohrung Ø8,6 und die vier
    Einsaetze sind seit Rev. 23 dieselben
    - Schrauben Garnitur -> Regal M3x10 -> M3x8 (3,5 mm Fla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
    [ToolheadZ.py, bauraum.py, toolhead_check.py]
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2026-09-24 Portal Rev. 9: Material-Abbruch in Fusion behoben
    Fusion brach beim zweiten Aluprofil ab: "RuntimeError: 2 :
    InternalValidationError : assetInst" bei body.material = ... Der Helfer
    kopierte Bibliotheksmaterialien (Aluminum 6061, Steel) per addByCopy
    unter ihrem eigenen Bibliotheksnamen; die erste Zuweisung ging, die
    zweite nicht. Jetzt wird das Bibliotheksmaterial direkt zugewiesen,
    kopiert werden nur noch die eigenen Materialien (PETG, PLA, Gummi).
    Ausserdem darf nichts Kosmetisches das Skript mehr abbrechen: eine
    gescheiterte Materialzuweisung und jedes Referenzteil, das sich nicht
    bauen laesst, landen im Bericht, und das Skript laeuft weiter. Im
    Nachbau geprueft, auch mit simuliertem Feh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
    [Portal.py]
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2026-09-30 Endschalter X: klarstellen, dass der Halter auf der 2020 sitzt
    Halter_X haengt schon in der vorderen Nut der 2020 (Portalrohr) und
    faehrt mit dem Portal; X und Y referenzieren damit unabhaengig
    voneinander, jede Lichtschranke an ihrem eigenen Eingang (X- D9, Y+ D10).
    endschalter.md, elektronik.md, verkabelung.md und die Lageskizze sagen das
    jetzt ausdruecklich. Keine Aenderung an Geometrie oder Verdrahtung.
    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
    [elektronik_zeichnen.py]
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2026-10-02 Portal Rev. 23, ToolheadZ Rev. 38: Spiel der Kette 0,5 mm, Löcher im Schlitten
    - kette_spiel 0,3 -> 0,5 mm je Seite in beiden Wannen und beiden
    Kettenhaltern (gedruckte Kette, Elefantenfuß). Damit vorn weiter 3 mm
    Luft zur Trägerplatte bleiben, liegt die X-Kette 0,2 mm weiter hinten
    (xk_y_vorn -5,3 -> -5,5, in beiden Skripten).
    - Schlitten_links hat die zwei Löcher für den Kettenhalter Y im Modell
    (seit Rev. 21); Kopf, Kommentar und Bericht sagen das jetzt
    ausdrücklich, die Bohrlehre bleibt für den schon gedruckten Schlitten.
    - portal_check: neue Prüfung Löcher Kettenhalter Y neben den Senkungen
    der Wagenschrauben (5,05 mm).
    - Zeichnungen neu erzeugt, Massen und Doku nac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
    [Portal.py, ToolheadZ.py, portal_check.py]
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2026-10-08 Motoren anschliessen: Steckplaetze am Shield und Adern je Achse
    tools/motoren_zeichnen.py -> docs/motoren-anschluss.svg:
    - Das CNC Shield V3 von oben wie im Gehaeuse (Reset oben links,
    Schraubklemme unten links): Motorstecker rechts neben jedem Treiber,
    Stifte von oben 2B 2A 1A 1B, Achsbuchstabe im Kaestchen darunter
    (oben links X, die uebrigen am Shield ablesen), A-Klon nur auf Y.
    - Je Achse die Adern der StepperOnline-Kabel: schwarz/gruen auf 2B 2A,
    rot/blau auf 1A 1B; am Y-Motor rechts schwarz und gruen getauscht.
    Zuordnung, Farben, Nummern und Laengen aus tools/verkabelung.py.
    verkabelung.md: Bild in Schritt 6. README: Datei, Werkzeug, Befehl.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
2026-10-08 STL fuer Haube und Kabelhalter, Kabelhalter Rev. 2
    tools/stl_export.py baut die Haube (Elektronik.py Rev. 3) und den
    Kabelhalter ohne Fusion nach: dieselben Masse aus lage(), Boolesche
    Operationen mit manifold3d, in Drucklage mit gestufter Fase gegen den
    Elefantenfuss. Er prueft Bauraum gegen lage(), schreibt binaere STL nach
    stl/ und meldet Volumen und Geschlecht (Haube 74,9 cm3, 12 Loecher;
    Kabelhalter 3,2 cm3, 2 Loecher).
    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
    [Elektronik_Deckel_r3.stl, Kabelhalter_r2.stl]
2026-10-09 Elektronik Rev. 4: runder Wippschalter, Kasten als STL
    Der Schalter ist rund, die Blende aussen 22,5 mm (Angabe 2026-10-09),
    nicht der eckige KCD1 19,2 x 12,9. Der Kasten bekommt ein Loch Ø20,2
    (bei dieser Blende ueblich, nicht gemessen), oben mit 45-Grad-Flanken
    0,6 mm ueber dem Kreis flach, damit es in der senkrechten Wand ohne
    Ueberhang druckt; die Blende deckt die Kappe. Die Wand bleibt innen auf
    1,6 mm verduennt (rund statt eckig). Sonst ist der Kasten wie Rev. 2,
    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
    [Elektronik_Deckel_r3.stl, Elektronik_Deckel_r4.stl, Elektronik_Gehaeuse_r4.stl]
2026-10-10 Pi Zero 2 W mit CNCjs statt PC, Pi-Halter Rev. 1
    Ein Raspberry Pi Zero 2 W steuert die Maschine ohne PC: LightBurn auf
    dem Mac speichert G-Code, CNCjs auf dem Pi schickt ihn ueber USB an den
    Uno, bedient wird im Browser. pi/ enthaelt das Einrichtungsskript
    (CNCjs 1.11.5 als Dienst, Ordner ~/gcode, sudoers fuer Herunterfahren
    und Neustart, WLAN-Energiesparen aus) und die Konfiguration mit Makros
    fuer Rahmen, Laserpunkt und Laser aus; mit CNCjs 1.11.5, visudo und
    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
    [PiHalter_r1.stl]
2026-10-10 Pi-Halter Rev. 2: 5-V-Wandler 63 x 30 mm
    Der Abwaertswandler 24 -> 5 V ist 63 x 30 mm (Angabe 2026-10-10), nicht
    hoechstens 60 x 30. Die Platte wird 3 mm breiter (178 mm, X -18 bis
    +160), der Pi rueckt 3 mm nach rechts; der USB-A-Stecker behaelt seine
    40 mm bis zum Pi. Die Hoehe des Wandlers ist weiter offen, Platz sind
    20 mm. Alle Abstaende bleiben (Portal 8,6 mm, Kasten 5,7 mm, Kabel
    8 mm), die Kauflaengen von W17-W19 auch.
    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
    [PiHalter_r1.stl, PiHalter_r2.stl]
2026-10-10 Pi: Wandler bestaetigt, Einschalten waehrend der Pi startet
    Der 5-V-Wandler ist hoechstens 20 mm hoch, Schraubklemmen und
    USB-A-Buchse sitzen an den schmalen Seiten (Angabe 2026-10-10). So ist
    der Halter seit Rev. 2 gebaut; nur die Markierungen werden [v], die
    Geometrie und stl/PiHalter_r2.stl bleiben.
    pi.md und verkabelung.md sagen jetzt, dass man mit dem Schalter nicht
    auf den Pi warten muss: Der Uno bekommt seine 5 V ueber USB, sobald der
    Pi Strom hat, GRBL laeuft nach etwa einer Sekunde und steht bis zur
    Referenzfahrt in ALARM.
    Claude-Session: https://claude.ai/code/session_01VmKH86cjZL8z1J9r11b32Z
2026-10-10 Pi-Halter Rev. 3: Haube ueber Pi und 5-V-Wandler
    Wie beim Elektronik-Kasten deckt jetzt eine gedruckte Haube Pi und
    Wandler ab. Ihre Waende (2 mm) stehen im Umriss der Platte auf ihr,
    3 x M3x8 halten sie in Messing-Einsaetzen M3 (D 5) in drei Domen der
    Platte (D 10, frei stehend). Die Dome enden 0,3 mm vor der Rueckwand,
    die Schrauben ziehen die Haube fest. Unten offen fuer Kabel und Zuluft,
    oben in der Rueckwand 6 Lueftungsschlitze 20 x 3 mm ueber Pi und
    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
    [PiHalter_Haube_r3.stl, PiHalter_r2.stl, PiHalter_r3.stl]
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2026-10-12 Vref: Anleitung fuer schon angeschlossene Motoren und den Pi
    Inbetriebnahme E sagt jetzt, dass angeschlossene Motoren bleiben duerfen
    (GRBL schaltet die Treiber im Stillstand ab, $1=25), wo die Messleitungen
    hinkommen, wie gedreht wird und dass die Haube dafuer abkommt. Die
    Einleitung erklaert, wie die Schritte ab D2 mit dem Pi statt dem Mac
    gehen. In F stand, die Motoren halten im Stillstand; mit $1=25 drehen sie
    sich von Hand.
    hardware-notizen.md: Schreibweisen des Messwiderstands und der Hinweis
    auf den Ersatztreiber.
    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
2026-10-12 Lichtschranken: Test vor der ersten Referenzfahrt
    Inbetriebnahme G nennt die Pruefung von Hand jetzt vor $H statt danach,
    dazu eine langsamere erste Suche ($25=200) und was ? danach meldet. D4
    erklaert das R im Pn: bei ausgeschaltetem Schalter. Unter den
    GRBL-Einstellungen steht, dass $22=1 vor $20=1 kommt, sonst error:10.
    Fehlersuche: ALARM:8 und ALARM:9 bei $H.
    toolhead-z.md: Nach $H stehen zwischen Gleitmutter und Kupplung 12 mm,
    nicht 11; GRBL zieht 1 mm vom Schaltpunkt zurueck.
    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
2026-10-12 Pi: GRBL vom Pi aus aufspielen
    Am Engraver blieb die Konsole von CNCjs stumm, ohne "Grbl 1.1h" nach dem
    Verbinden. pi.md beschreibt jetzt, wie GRBL 1.1h mit avrdude vom Pi aus
    auf den Uno kommt, ohne W17 umzustecken: fertiger Build von GitHub mit
    SHA-256 zum Vergleich, CNCjs vorher aus, danach $I mit [OPT:V,15,128].
    Dazu der Hinweis auf $SLP im Menue des Grbl-Widgets und je eine Zeile in
    der Fehlersuche von pi.md und verkabelung.md (GRBL fehlt oder W16 haelt
    den Uno im Reset). Inbetriebnahme D1 und die Einleitung verweisen darauf.
    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
